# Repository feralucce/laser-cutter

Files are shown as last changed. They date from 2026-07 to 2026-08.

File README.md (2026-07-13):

# DIY Laser Cutter / Engraver

Design and build log for a homemade laser cutter and engraver.

## Repo layout

- `docs/decisions/` — Architecture Decision Records (ADRs). Each significant design choice (frame material, laser type/power, motion system, controller board, software stack, safety systems, etc.) gets its own numbered record: context, decision, consequences.
- `docs/` — general design notes, reference material, specs.

## Status

Just getting started. See `docs/decisions/` for the running log of decisions as we make them.

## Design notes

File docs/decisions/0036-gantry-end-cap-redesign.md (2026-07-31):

# 0036. Gantry end cap redesign: flat straddle plate, both ends identical

Date: 2026-07-14
Status: Superseded by [0047](0047-captured-belt-custom-plates.md) (supersedes [0016](0016-gantry-end-plate-rework.md) entirely)

## Context

[0016](0016-gantry-end-plate-rework.md)'s laminated fixed/floating
asymmetric pair existed to solve one problem: absorbing the 800mm beam's
length tolerance without needing an exact pre-cut length, since one end
had to be a precise reference and the other had to float.

[0035](0035-frame-corner-topology-rework.md) moves that tolerance-absorbing
job to the main frame's own corner joint (1200mm pieces sliding against
the 800mm end pieces before squaring). That removes the entire reason for
an asymmetric pair — **both gantry end caps can now be identical, flat,
and fully solid**, which is also the more rigid ("solid AF") joint that
motivated revisiting this in the first place.

The new topology ([0035](0035-frame-corner-topology-rework.md)) also
changes what this plate needs to physically span: the X-carriage (MGN12H
block) now rides on the **outside face** of the 1200mm frame piece, while
the beam sits at the gantry's own position along that rail. The end cap
plate needs to reach from the beam's end, across/past the 1200mm frame
piece, down to that carriage block — confirmed against a reference diagram
([docs/reference/frame-topology-sketch.svg](../reference/frame-topology-sketch.svg))
showing the relative positions of the 1200mm frame (red),
800mm end pieces (blue), the 800mm gantry beam (magenta), and the gantry
end caps (gold) straddling across the 1200mm rail to reach the carriage.

## Decision

One plate **design**, but each beam-end joint uses a **front + back pair**
(sandwiching the beam) — 2 ends x 2 plates (front, back) = 4 plate
assemblies total, all built from the same design (front and back are the
same shape; "both ends identical" means left-end pair = right-end pair).

- Each plate: **2 laminated layers, 3mm black acrylic** (6mm total) —
  thinner per-layer than [0029](0029-laser-cut-material-selection.md)'s
  general 5mm rule, a deliberate exception given these are now doubled up
  (front+back per end, 4 plates instead of 1) and don't need the
  T-slot-channel-replicating lamination trick [0016](0016-gantry-end-plate-rework.md)
  used ([0029](0029-laser-cut-material-selection.md) remains the default
  elsewhere, with this as a noted exception).
- **Beam attachment zone** (top of each plate): 3 connection points per
  plate (6 total per end, split across the front/back pair) —
  - 1 tapped screw into the beam extrusion's end bore (2040 has two
    internal channels; front plate uses one, back plate uses the other)
  - 2 L-bracket legs into that plate's own facing wide face's 2 T-slots
    (front plate → front wide face; back plate → back wide face) — outer
    layer solid, inner layer has cutouts for the L-brackets, same
    lamination principle as [0016](0016-gantry-end-plate-rework.md), just
    applied to both plates now instead of one.
- **Straddle zone** (middle of each plate): extends down/across, clearing
  the 1200mm frame piece's position, to reach the carriage block. Working
  estimate for this span — needs confirming once the beam/rail/carriage
  stack-up is physically known, same caveat pattern used for the Y-axis
  carriage bracket ([0032](0032-y-axis-laser-carriage.md)).
- **Carriage attachment zone** (bottom of each plate): MGN12H's standard
  20x20mm M3 bolt pattern, same as used throughout this build
  ([0013](0013-gantry-end-plate-design.md)) — both plates in the pair bolt
  through to the same block, sandwiching it.

Category: laser cut, 3mm black acrylic ([0003](0003-parts-sourcing-constraint.md)).

Design file: [hardware/laser-cut/gantry-end-cap.svg](../../hardware/laser-cut/gantry-end-cap.svg)
(one design, cut 8x total — 2 layers x 2 plates x 2 ends).

## Consequences

- Both gantry end caps are now identical — one design instead of two,
  simpler to cut/laminate/stock spares for.
- Bracket count for the gantry: **8 L-bracket legs total** (4 per end x 2
  ends) — both wide faces of the beam are now used at both ends, not just
  one face at one end as [0016](0016-gantry-end-plate-rework.md) originally
  had. This matters for [0028](0028-corner-bracket-hardware-selection.md)'s
  purchase quantity — revisit that count.
- Plus 4 tapped screws total (2 per end) — not L-brackets, ordinary M5
  bolts into the extrusion's own tapped end bore, no separate hardware
  purchase needed beyond generic screws.
- The old `gantry-end-plate-fixed.svg` and `gantry-end-plate-floating.svg`
  files are removed from the repo (superseded, preserved in git history) —
  a single new design file, `gantry-end-cap.svg`, replaces both.
- The straddle-zone span is a working estimate, not yet verified against
  physical assembly — same treatment as other "verify once hardware is in
  hand" items throughout this build.
- 2026-07-14 correction: the first version of `gantry-end-cap.svg` had the
  L-bracket slots at the wrong scale/orientation (10mm wide x 22mm tall,
  side by side) and one slot positioned entirely past the extrusion's real
  40mm-tall footprint (y=56-78 against an actual 8-48 span). Fixed by
  adding a dashed reference rectangle showing the true 20x40mm extrusion
  cross-section, and repositioning both slots (now 22mm wide x 10mm tall,
  rotated to match the wide-face-vertical orientation) fully within that
  reference. Slot dimensions remain a working estimate — redraw once the
  actual corner bracket's leg dimensions are confirmed
  ([0028](0028-corner-bracket-hardware-selection.md)), but they should now
  at least be plausibly located on the real material rather than floating
  in empty space.

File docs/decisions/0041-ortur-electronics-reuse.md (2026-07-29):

# 0041. Motion electronics: reuse Ortur LM2 S2 controller, drivers, motors, wiring, switches

Date: 2026-07-29
Status: Accepted (supersedes [0011](0011-x-axis-dual-motor.md), [0017](0017-stepper-motor-selection.md),
[0022](0022-controller-board-selection.md), [0026](0026-t41u5xbb-pin-mapping.md),
[0027](0027-grblhal-auto-square-config.md), [0037](0037-stepper-driver-selection.md))

## Context

This machine started as a ground-up custom build: new frame, new motion
system, and new electronics (grblHAL T41U5XBB + Teensy 4.1 controller,
STEPPERONLINE NEMA17 motors, STEPPERONLINE DM542T drivers), because the
project's starting point — an Ortur LM2 S2 already extended to 800x1200mm
with a 10W module — was assumed to need dual independently-driven,
firmware-synced X motors ([0011](0011-x-axis-dual-motor.md)) to keep a
1200mm-span gantry square, and the Ortur's stock closed-firmware GRBL
1.1f board can't do that kind of ganged/auto-square axis at all.

That assumption turns out to be wrong for this build. The Ortur LM2 S2,
at this exact 800x1200mm frame size, already drives its gantry/rail axis
(800mm, per [0043](0043-adopt-ortur-axis-convention.md)) with a **single
NEMA17 motor whose shaft is extended (via coupler + standoff) to reach
across and drive both sides of the gantry from one continuous shaft** —
manually squared once and locked in place. Squaring is inherent to the
mechanism (both sides are physically the same rotating shaft, not two
motors being kept in sync), not a firmware or electronic concern at all.
This is close to, but not exactly, the "single motor + mechanical link"
option [0011](0011-x-axis-dual-motor.md) originally considered and
rejected in favor of firmware ganging; that rejection was based on a
shaft/belt coupling across a long span being an unproven risk. It isn't
unproven — the Ortur has been cutting with a 10W module at this exact
frame size using exactly this mechanism. A K40-compatible adapter board
exists that lets the Ortur's stock controller drive the K40 laser module
in place of its own diode driver, closing the last gap (laser control)
that seemed to require a new controller.

Reusing the Ortur's controller, drivers, motors, wiring, and switches
removes the entire custom-electronics scope this project had taken on
(controller board selection/wiring/firmware, driver selection, motor
selection) without weakening anything — the mechanism is already proven
at this machine's actual size and load class, just with a lighter head.

## Decision

**Reuse from the existing Ortur LM2 S2 build, as-is:**
- Controller board (stock, GRBL 1.1f firmware)
- Stepper drivers (whatever the Ortur board integrates/uses)
- Steppers: **1 motor with an extended shaft (coupler + standoff) driving
  both sides of the gantry** on the rail/gantry-travel axis (Y, 800mm,
  per [0043](0043-adopt-ortur-axis-convention.md)); 1 separate motor on
  the beam/carriage axis (X, 1200mm) — this replaces this build's earlier
  assumption of 2 independently-driven motors on that axis
- Wiring harness
- Limit switches (X and Y homing switches)
- Laser control: via a K40-compatible adapter board that translates the
  Ortur controller's laser-control output to what the K40 module expects
  — exact product/model not yet identified, needs sourcing

**Squaring**: inherent to the mechanism — one continuous shaft (coupler +
standoff) turns both sides of the gantry together, so there's nothing to
electronically keep in sync. Squaring is a one-time mechanical alignment
at assembly (shaft/coupler position, locked with set screws), not a
runtime or firmware concern. No `$8`/`$170`/`$347-349` tuning, no
ganged-axis firmware build, and — unlike the originally-considered dual-
motor approach — no possibility of the two sides drifting out of sync
over time, since they're mechanically one shaft.

**Superseded ADRs**, no longer applicable to this build:
- [0011](0011-x-axis-dual-motor.md) — the "two independently-driven
  motors, synced in firmware" approach doesn't apply at all; this axis
  uses one motor and one continuous extended shaft instead
- [0017](0017-stepper-motor-selection.md) — motors are reused from the
  Ortur, not purchased
- [0022](0022-controller-board-selection.md) — controller is the Ortur's
  own stock board, not a new grblHAL Teensy build
- [0026](0026-t41u5xbb-pin-mapping.md) — no T41U5XBB in this build, pin
  mapping is moot
- [0027](0027-grblhal-auto-square-config.md) — no firmware auto-squaring;
  squaring is mechanical, done once at assembly
- [0037](0037-stepper-driver-selection.md) — drivers are reused from the
  Ortur, not purchased

**Still valid, unaffected by this ADR:**
- Frame dimensions/footprint ([0009](0009-frame-dimensions-final.md),
  [0035](0035-frame-corner-topology-rework.md)) and extrusion profile
  ([0010](0010-extrusion-profile-2040.md)) — new 2040 frame + gantry beam
  still being built, just carrying reused motion electronics instead of
  new ones
- Laser module selection ([0002](0002-laser-module-selection.md)) — K40
  unchanged
- Axis topology/naming ([0014](0014-axis-naming-convention.md)) — X/Y
  roles unchanged
- Gantry plates ([0040](0040-x-axis-v-wheel-gantry.md)) and laser
  carriage ([0032](0032-y-axis-laser-carriage.md)) — both already flagged
  as open, not-yet-designed work; unaffected by which controller drives
  the motors that move them

## Consequences

- Eliminates essentially the entire custom-electronics track of this
  project: no controller board to solder/wire/flash, no driver modules
  to mount, no motors to source, no firmware ganging to configure, no
  runtime `$` squaring tuning to commission.
- New open item: identify and source the specific K40-compatible adapter
  board that lets the Ortur's stock controller drive the K40 module —
  not yet a named product.
- Limit switch mounting design ([0033](0033-limit-switch-selection.md))
  is still real, open work (the new 2040 frame needs its own switch
  mounts), but the switch part itself and its hole spacing are now a
  known/reused quantity rather than an estimate pending physical
  hardware.
- Wiring harness is reused rather than newly run — the existing wiring
  diagram ([docs/reference/wiring-diagram.svg](../reference/wiring-diagram.svg))
  and fusing/gauge ADRs ([0025](0025-24v-rail-fusing.md),
  [0030](0030-24v-wire-gauge.md)) described a from-scratch harness for
  the new controller; that harness plan no longer applies and should be
  treated as historical, not a task to execute.
- The custom-controller design this project had built up through 2026-07-29
  is preserved in full on the `custom-controller-fallback` git branch, in
  case the Ortur-reuse approach hits a hardware blocker (e.g. the K40
  adapter board doesn't exist/work as expected) and this project needs to
  fall back to it.

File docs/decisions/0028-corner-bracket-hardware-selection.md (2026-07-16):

# 0028. Corner bracket hardware: product selection (dimension verification still pending)

Date: 2026-07-14
Status: Accepted

## Context

[0012](0012-corner-joints-and-feet.md) and [0016](0016-gantry-end-plate-rework.md)
both describe using "inside hidden corner bracket" style hardware (an
L-shaped cast bracket, one leg per T-slot face, tightened with a set
screw) for the frame corners and the gantry end plates — but neither ADR
ever linked a specific product. 0016 used working numbers (~19-20mm leg
length, M5 set screw, sized for a 6mm-wide/5.5mm-deep slot channel) and
flagged them as unverified.

Checked every retailer carrying this part style (Amazon, MakerTechStore,
OpenBuilds official store, Bulkman3D, RatRig, Maker Store) looking for a
dimensioned drawing. **None publish the leg length or set-screw position**
— this is a generic cast-zinc-alloy part cloned across many sellers, and
the only consistently published numbers are the overall footprint
(~25x10mm) and that the 20-series version takes M5 set screws. The 6mm
slot-channel width in 0016's working numbers is actually just the 20-series
T-slot extrusion's own standard channel width ([0010](0010-extrusion-profile-2040.md)),
not something specific to this bracket — that part of the working number
is solid. The leg length and set-screw offset genuinely cannot be
confirmed from any spec sheet; they can only be measured once a physical
unit is in hand.

## Decision

Purchase **[Inside Hidden Corner Bracket, 90°, M5 set screws, for 20mm x
20mm / 2020 / 20-series T-slot extrusion](https://www.amazon.com/Pack-Inside-Hidden-Corner-Bracket/dp/B06XZ3Z82M)**
(20-pack).

Quantity needed, updated 2026-07-15: **8** for the gantry (4 per end x 2
ends — both wide faces of the beam are now used at both ends, per the end
cap redesign, [0036](0036-gantry-end-cap-redesign.md)) + **8** for the
main frame rectangle corners (**2 per corner** — one bracket in each
T-slot at every corner, not just one, for a stronger joint than
[0012](0012-corner-joints-and-feet.md)'s original single-bracket-per-corner
default) = **16 total**, still covered by the 20-pack, now with only 4
spares.

Category: off-the-shelf.

## Consequences

- Closes the "which product" gap — there's now a specific SKU to order,
  where before there was only a hardware category description.
- Does **not** close the dimension-verification gap flagged in
  [0016](0016-gantry-end-plate-rework.md) — leg length and set-screw
  position remain working estimates until this specific part is physically
  in hand and measured with calipers. Cut the end plates only after that
  verification, or expect to re-cut if the slot/access-hole dimensions are
  off.
- The 6mm slot-channel width in the current end-cap design
  ([hardware/laser-cut/gantry-end-cap.svg](../../hardware/laser-cut/gantry-end-cap.svg),
  [0036](0036-gantry-end-cap-redesign.md)) is confirmed correct regardless
  (fixed by the extrusion standard, not the bracket) — only the slot depth
  and access-hole position depend on the actual bracket and remain
  unverified.

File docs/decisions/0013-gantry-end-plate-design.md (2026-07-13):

# 0013. Gantry end plate design

Date: 2026-07-13
Status: Accepted

## Context

The gantry crossbeam (2040, per [0010](0010-extrusion-profile-2040.md)) needs
to attach to the two Y-axis MGN12 carriage blocks
([0008](0008-motion-system-mgn12-rails.md), [0014](0014-axis-naming-convention.md))
at each end — the carriages riding the two guide rails that the whole
gantry travels along. Both mounting
interfaces are flat faces, which allows a single flat laser-cut plate rather
than a bent/welded bracket:

- The MGN12H carriage block has a 20mm x 20mm M3 bolt pattern on its top
  face.
- The 2040 beam's wide (40mm) face has two T-slots spaced 20mm apart,
  matching the standard 20-series M5 T-nut/screw standard.

The beam's end sits on top of the plate (screwed down into its own T-slots
via T-nuts), and the carriage block sits underneath (screwed up into its
threaded top holes) — no bent metal or 3D-printed part needed.

## Decision

Laser-cut flat plate, 50mm x 90mm, 3mm corner radius:

- Two M5 clearance holes (5.5mm dia), 20mm apart, centered on the plate
  width — for the 2040 beam's T-slot mounting.
- Four M3 clearance holes (3.5mm dia) in a 20x20mm square pattern — for the
  MGN12H carriage block.
- 15mm minimum edge margin around all holes for material strength in
  plywood/acrylic.

Design file: [hardware/laser-cut/gantry-end-plate.svg](../../hardware/laser-cut/gantry-end-plate.svg).
Category: laser cut ([0003](0003-parts-sourcing-constraint.md)).

## Consequences

- No 3D-printed or bent-metal bracket needed for this joint — a flat plate
  cut on the current laser handles it.
- Plate material/thickness not yet chosen (plywood vs acrylic, thickness) —
  needs to be picked before cutting; 15mm edge margins give some flexibility
  here.
- Two of these plates needed per machine (one per side of the gantry).
- All future laser-cut SVGs for this project include a 100mm x 10mm scale
  bar for import verification, per standing convention.
- **Open issue**: the gantry beam spans the long/flexible axis (X, up to
  1219mm) — it connects the two Y-axis guide rails, which are spaced apart
  by this dimension. The beam must be shorter than that spacing — it spans
  between the two carriages, which sit inboard of the Y-rails (mounted on
  the extrusion's inward-facing wide face). Exact beam length = the chosen
  X-axis spacing minus the Y-rail extrusion width, MGN12 rail/carriage
  offset, and this end plate's thickness, on both sides. Not yet
  calculated — needs final rail offset and plate material thickness before
  cutting the beam to length.
  Separately, the two **Y-axis guide rails themselves** are each 800mm long
  (the fixed axis, [0007](0007-frame-footprint-constraints.md)) — that
  figure is not affected by this clearance issue, since it's the guide
  rails' own length, not the beam's span.

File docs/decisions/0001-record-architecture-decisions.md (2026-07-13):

# 0001. Record decisions as ADRs

Date: 2026-07-13
Status: Accepted

## Context

This is a from-scratch DIY laser cutter/engraver build. We'll be making many
consequential choices (frame, laser source, motion system, electronics,
firmware/software, enclosure, safety systems) over time, and want a durable
record of why each choice was made, not just what was chosen.

## Decision

Record each significant design decision as a numbered markdown file in
`docs/decisions/`, following `template.md`. Use sequential numbering
(0001, 0002, ...). Mark a record "Superseded by NNNN" rather than editing
history when a decision changes.

## Consequences

Slight overhead per decision, but gives us a searchable history and lets
future us (or collaborators) understand the reasoning instead of just the
current state of the build.

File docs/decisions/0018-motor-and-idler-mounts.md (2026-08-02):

# 0018. Motor mount and idler mount hardware

Date: 2026-07-13
Status: Superseded by [0048](0048-captured-belt-both-axes-no-idler.md) (idler pulley/mount no longer needed; motor mount still applies where reused motors attach)

## Context

[0015](0015-x-axis-motor-system.md) decided motor and idler mounts should
be off-the-shelf (not 3D printed), since both are constantly-tensioned
anchor points where PLA-CF creep/flex would be a risk. Needed: specific
purchasable parts for both.

For the idler specifically: it only ever contacts the belt's smooth back
side (the toothed side stays engaged with the motor's drive pulley around
the whole loop), so the idler itself doesn't need teeth — a smooth pulley
or even a plain bearing works correctly. No clean single "bracket + pulley"
kit product was found; the standard/simpler approach is a smooth idler
pulley spinning freely on a bolt threaded into a T-nut in the extrusion
slot — fully off-the-shelf hardware, tension adjustable by sliding the
T-nut position before tightening, no dedicated bracket part needed.

## Decision

- **Motor mount**: [Socobeta 5PCS NEMA17 Stepper Motor Mounting
  Plate/Bracket, for 2020/2040 extrusion](https://www.amazon.com/Socobeta-Stepper-Mounting-Bracket-Aluminum/dp/B0FPMDHTHD).
  5-pack covers the 3 motors needed (2x X-axis, 1x Y-axis,
  [0011](0011-x-axis-dual-motor.md)) with 2 spares.
- **Idler mount**: bolt-on-T-nut approach (M5 socket-head bolt + washers/
  spacers for height + T-nut), no separate bracket product.
- **Idler pulley**: [DiGiYes GT2 Timing Belt Idler Pulley, 20-toothless
  (smooth), 5mm bore, for 6mm belt width](https://www.amazon.com/gp/product/B0BSPC7D9S/).
  User-sourced. Matches requirement: smooth-riding (teeth not required, and
  this part is genuinely toothless rather than a repurposed drive pulley),
  5mm bore (matches M5 bolt and the [0017](0017-stepper-motor-selection.md)
  motor's shaft size for hardware consistency), sized for the 6mm GT2 belt
  ([0015](0015-x-axis-motor-system.md)).

**Update (2026-07-29)**: the bolt-on-T-nut hardware approach above assumed
buying the OpenBuilds-style bolt+spacer+locknut kit for the idler mount —
that kit is no longer available. Switching to a **3D-printed PLA-CF idler
mount** instead: [JeSc HyperCube XY Idler T16 v2.0](https://www.printables.com/model/56963-jesc-hypercube-xy-idler-t16-v20/files)
(originally a HyperCube CoreXY 3D printer part), downloaded to
[Printables/](../../Printables/) in this repo. User already has PLA-CF
filament on hand.

This reopens the concern this ADR's own Context section originally raised
against printing the idler mount — "constantly-tensioned anchor points
where PLA-CF creep/flex would be a risk" — but it's directly addressed:
**printing solid (100% infill)**, not the typical partial-infill
approach. Solid PLA-CF removes the creep/flex mechanism that concern was
about (infill-cavity walls slowly deforming under sustained load); a
solid print behaves much closer to a machined block than a typical
lightweight 3D print. Accepted as resolved, not just deferred.

User will also modify the model file directly if the pulley mount
geometry doesn't fit the DiGiYes idler once test-fit — treat the
Printables download as a starting point, not a fixed, unmodifiable file.

**Not yet verified**: whether the print's pulley bore/mount geometry
fits the already-purchased [DiGiYes GT2 20T idler pulley](https://www.amazon.com/gp/product/B0BSPC7D9S/)
as downloaded, before any modification. Tooth count isn't the concern —
idler pulleys are smooth/toothless by design (this build's own reasoning
above, and presumably true of the original HyperCube idler this print was
made for too), so the "T16" in the model's name is about GT2 belt-pitch
compatibility generally, not a mismatched mating tooth count. What
actually needs checking is the idler's physical bore diameter, outer
diameter, and width against what this bracket's mount was sized for —
same "verify against physical hardware" pattern used throughout this
build's other parts, with the fallback that it's a known-editable file
if it doesn't.

**Print settings**: PLA-CF, **100% (solid) infill** — deliberately
different from this build's other printed parts, which use 15% infill
([0040](0040-x-axis-v-wheel-gantry.md)); solid infill specifically to
resolve the creep/flex concern for this constantly-tensioned part.

Category: mostly off-the-shelf (idler pulley, motor mounts); idler mount
bracket now 3D-printed PLA-CF instead of off-the-shelf hardware.

## Consequences

- One consistent hardware size (5mm/M5) across idler bore, idler mounting
  bolt, and motor shaft — simplifies the parts list.
- Idler tensioning is manual (slide T-nut, tighten) rather than a
  dedicated adjustable-slot bracket mechanism — simple but requires loosening
  and re-tightening the bolt to adjust tension, rather than a quick-adjust
  slot.
- Idler pulley now sourced — motor-side pulley hardware list
  ([0017](0017-stepper-motor-selection.md), [0019](0019-drive-pulley-selection.md),
  this ADR) is complete.

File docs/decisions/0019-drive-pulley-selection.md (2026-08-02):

# 0019. Drive pulley (motor gear) selection

Date: 2026-07-13
Status: Superseded by [0048](0048-captured-belt-both-axes-no-idler.md) (captured-belt drive pulley now mounts between the wheels directly on both axes)

## Context

[0015](0015-x-axis-motor-system.md) specified GT2 20-tooth, 5mm bore
pulleys for the motor side of each belt loop, but no specific product had
been sourced yet.

## Decision

**[BEMONOC 2GT Timing Pulley, 20 teeth, 5mm bore, for GT2 6mm belt](https://www.amazon.com/BEMONOC-Timing-Pulley-Teeth-Printer/dp/B014ID115W)**

Matches spec exactly: 20-tooth, 5mm bore (fits the
[0017](0017-stepper-motor-selection.md) motor's shaft), sized for the 6mm
GT2 belt ([0015](0015-x-axis-motor-system.md)), set-screw mounting.

Quantity: 3 (one per motor — 2x X-axis, 1x Y-axis, [0011](0011-x-axis-dual-motor.md)).

Category: off-the-shelf.

## Consequences

- Completes the drive-side hardware list for the belt loops: motor
  ([0017](0017-stepper-motor-selection.md)), drive pulley (this ADR),
  idler pulley (pending link, [0018](0018-motor-and-idler-mounts.md)),
  motor mount ([0018](0018-motor-and-idler-mounts.md)).
- Still open: belt clamp/clip to anchor the belt to each carriage.

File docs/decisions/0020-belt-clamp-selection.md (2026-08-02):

# 0020. Belt clamp selection and mounting

Date: 2026-07-13
Status: Superseded by [0048](0048-captured-belt-both-axes-no-idler.md) (captured belt now on both axes; belt ends anchored by the GT2 fixing clamp instead)

## Context

[0015](0015-x-axis-motor-system.md) flagged the belt clamp (anchoring each
belt end to the carriage) as an open item. Each X-rail runs an open belt
loop — both ends terminate at clamps on the same carriage/end plate, rather
than a single continuous loop — so tension can be fine-adjusted
independently at each end by how far the belt is threaded through its
clamp before tightening.

## Decision

**[3DMAN GT2 Timing Belt Aluminum Gear Clamp Mount Block, 9x40mm, for 6mm
belt width (10-pack)](https://www.amazon.com/3Dman-Timing-Aluminum-Clamp-9X40mm/dp/B08XVVQW6G/)**

40 x 9 x 5mm aluminum block, single 4.5mm center mounting hole (M4 screw).
10-pack covers the 4 needed (2 per side x 2 sides) with spares.

**Mounting**: one clamp per belt end, both on the same gantry end plate
([0016](0016-gantry-end-plate-rework.md)) since both belt ends terminate at
the same carriage. Added to the **outer layer** of each end plate (fixed
and floating), in the left/right margins beside the existing carriage-mount
hole pattern, oriented with the clamp's 40mm length running parallel to the
plate's long axis (matching the belt's direction of travel along the
X-rail):

- Clamp hole 1: (6, 65) — left margin
- Clamp hole 2: (44, 65) — right margin

Both positions verified clear of the existing 4x M3 carriage-mount holes
(at x=15/35) and the plate edges/corner radius.

Category: off-the-shelf.

## Consequences

- Closes out the last open item from [0015](0015-x-axis-motor-system.md)'s
  belt/pulley hardware list.
- Exact clamp position is a reasonable placement based on published
  dimensions, not verified against a physical mockup — worth confirming
  the belt actually reaches both clamp points cleanly once the carriage,
  rail, motor, and idler are physically laid out; may need minor
  adjustment.
- Both end plate SVGs ([hardware/laser-cut/gantry-end-plate-floating.svg](../../hardware/laser-cut/gantry-end-plate-floating.svg),
  [hardware/laser-cut/gantry-end-plate-fixed.svg](../../hardware/laser-cut/gantry-end-plate-fixed.svg))
  updated with these 2 holes on the outer layer.

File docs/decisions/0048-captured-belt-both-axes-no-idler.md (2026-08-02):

# 0048. Captured belt drive on both axes; idler pulleys eliminated

Date: 2026-07-31
Status: Accepted (extends [0047](0047-captured-belt-custom-plates.md) to X; supersedes [0018](0018-motor-and-idler-mounts.md)'s idler pulley/mount, [0019](0019-drive-pulley-selection.md) where it specified an idler-loop system)

## Context

[0047](0047-captured-belt-custom-plates.md) adopted captured-belt drive
for the Y-axis (short, 800mm, dual-rail/shaft-driven) gantry plates.
The X-axis (long, 1200mm, single-motor carriage) had been left on the
original open-loop belt design (drive pulley + idler pulley + belt
clamps at each end).

User has now extended captured-belt routing to X as well. A captured
belt path doesn't need a separate idler pulley — the belt threads
directly under the traveling wheels rather than needing a dedicated
return pulley at the far end of an open loop. This removes the idler
pulley (and its mount) from the design entirely, on both axes.

## Decision

- Captured belt drive on **both axes** (X and Y), not just Y.
- **DiGiYes idler pulley**: no longer needed anywhere in the design.
- **Idler mount bracket** (JeSc HyperCube XY Idler T16 v2.0, the
  project's last remaining 3D-printed part): no longer needed, removed
  from `hardware/3d-printed/`.
- **The GT2 fixing clamp becomes the only 3D-printed part in this
  build**: [hardware/3d-printed/gt2-fixing-clamp.stl](../../hardware/3d-printed/gt2-fixing-clamp.stl)
  (source: user-downloaded model, "gt2-belt-clamp-techguy"). Anchors the
  captured belt's ends. Qty: **8** (per-axis-end anchor points across
  both axes). Print PLA-CF, solid (100% infill) — same creep-resistance
  rationale already established for this project's other tensioned
  printed parts.
- `hardware/3d-printed/` cleaned out — all previously-superseded
  drafts (limit-switch-mount, shaft-far-end-bearing-mount,
  y-carriage-k40-bracket, y-gantry-plate) removed outright rather than
  kept for reference, since none of them represent live geometry
  anymore and this project's git history already preserves them if
  ever needed.

## Consequences

- BEMONOC drive pulley and 3DMAN belt clamp purchases (0019/0020) are
  no longer part of this design on either axis — captured belt uses the
  drive pulley mounted between the wheels directly, and the GT2 fixing
  clamp anchors the belt ends instead of the 3DMAN clamps.
- BOM updated: DiGiYes idler pulley removed from Motion system; 3D-printed
  parts section now lists only the GT2 fixing clamp, qty 8.
- Belt clamp/idler pulley hardware already purchased for the original
  open-loop design is simply not part of this design going forward —
  not something to manage or return, the user's own call.

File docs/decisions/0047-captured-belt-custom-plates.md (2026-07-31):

# 0047. Y-axis gantry plates: back to captured belt, custom laser-cut acrylic

Date: 2026-07-29
Status: Accepted (supersedes [0046](0046-shaft-driven-open-belt.md); reinstates the captured-belt approach from [0042](0042-captured-belt-drive.md))

**Also supersedes**: [0036](0036-gantry-end-cap-redesign.md) — this Y
gantry plate design *is* the gantry end cap, doing the same job
(terminating the beam, mounting to the gantry plates); it isn't a
separate part alongside `gantry-end-cap.svg`. That file and this ADR's
carriage-attachment-zone open item are both closed out by this design.

## Context

[0046](0046-shaft-driven-open-belt.md) moved away from captured-belt
routing specifically to avoid needing to match the purchased aluminum
V-wheel plate's exact wheel geometry. That constraint is now gone: the
user is designing **custom gantry plates from scratch** (reusing only
the wheels/wheel-bolts from the purchased kit, not the kit's own plate),
directly informed by two real reference files
(`Printables/yplateleft.stl`, `Printables/yplateright.stl`) that already
solve this exact captured-belt layout — motor or bearing centered, 2 top
wheels flanking the shaft, a bottom wheel, and 2040 mounting holes. With
a real reference geometry in hand, captured-belt is no longer a fitting
problem — it's just a matter of drawing the plate.

Two further changes from that reference:
- **3 bottom wheels instead of 1** (2 top unchanged) — more load support
  under the gantry's weight, all 3 using the same wide/eccentric-nut-
  clearance hole style the reference used for its single bottom wheel.
- **4 additional M5 holes per plate for corner L-brackets** — the
  "FOR 20 SERIES ALUMINUM PROFILE RAIL" corner bracket (26mm tall leg,
  25mm long leg, M5, hole 6mm in from the bend), seated in the 2040
  beam's own V-slot channel and bolted to the plate, for squareness/
  rigidity — not a flat face-mount bracket.
- **Material: laser-cut black acrylic, not 3D-printed PLA-CF.** The
  shaft-far-end bearing bracket ([shaft-far-end-bearing-mount.scad](../../hardware/3d-printed/shaft-far-end-bearing-mount.scad))
  and the first pass at this plate ([y-gantry-plate.scad](../../hardware/3d-printed/y-gantry-plate.scad))
  were both designed as 3D-printed parts before this correction — both
  superseded, kept for reference/coordinate history only.

## Decision

**Design file**: [hardware/laser-cut/y-gantry-plate.svg](../../hardware/laser-cut/y-gantry-plate.svg)
— **authored directly by the user in Inkscape** (my earlier programmatic
draft was replaced outright, not merged), two variants (motor side,
bearing side).

**Attachment to the 2040 beam: 6 points per plate**:
- **2 tapped directly into the extrusion's end grain** (threaded holes,
  not T-slot) — positioned near the shaft/motor bore
- **4 through slotted holes for 20-series corner L-brackets** (the ones
  seated in the extrusion's V-slot, see the "FOR 20 SERIES ALUMINUM
  PROFILE RAIL" hardware from earlier conversation) — **slotted, not
  round**, specifically because no reliable dimensional reference exists
  for that hardware to place a fixed hole accurately; slots absorb the
  uncertainty, same philosophy as this project's other not-yet-verified
  parts (idler mount, corner brackets)

Other hole layout (both variants share everything except the center
mount) matches the reference plates and my earlier draft's data — 2 top
wheels, 3 bottom wheels (wide/eccentric-nut style), NEMA17 or 625ZZ
bearing at center. The outer boundary is a plain rectangle (~87.26mm x
~160.75mm), not the organic shield shape from the reference STLs — the
user deliberately simplified it, matching the same call I'd made
independently in the draft this supersedes.

**Superseded**: [0046](0046-shaft-driven-open-belt.md) (open belt loop,
2 pulleys) — captured-belt routing from [0042](0042-captured-belt-drive.md)
is reinstated. [0018](0018-motor-and-idler-mounts.md)'s idler
pulley/mount and [0019](0019-drive-pulley-selection.md)'s drive pulley
selections still apply to the X-axis (unaffected), but no longer apply
to the Y-axis the way 0046 had them wired up.

## Consequences

- The purchased BEMONOC/DiGiYes pulleys and 3DMAN belt clamps
  ([0046](0046-shaft-driven-open-belt.md)'s reinstated hardware) are no
  longer part of the Y-axis mechanism — still usable on X, which keeps
  its own motor/pulley/belt-clamp setup unaffected by this ADR.
- Wheels and wheel-bolts are reused from the purchased aluminum V-wheel
  plate kit (0040) — its own plate is not used, only its wheel hardware.
- **Not yet confirmed**: acrylic thickness isn't specified in the SVG
  itself (project default is 5mm, 0029; reference 3D-printed plates were
  8mm) — worth a real check before committing to a full cut.
- Bottom wheel X-alignment is resolved — the user's own file confirms
  the layout, no longer an open question.
- 3D-printed versions of both the gantry plate and the far-end bearing
  bracket are superseded and kept only for reference/coordinate history,
  not built.

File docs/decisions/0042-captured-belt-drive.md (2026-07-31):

# 0042. Belt routing: captured belt drive (Ortur style), not clamped-both-ends

Date: 2026-07-29
Status: Reinstated by [0047](0047-captured-belt-custom-plates.md) (briefly superseded by [0046](0046-shaft-driven-open-belt.md)) (supersedes [0020](0020-belt-clamp-selection.md); modifies
[0018](0018-motor-and-idler-mounts.md), [0019](0019-drive-pulley-selection.md),
[0040](0040-x-axis-v-wheel-gantry.md))

## Context

[0020](0020-belt-clamp-selection.md) designed an open belt loop with both
ends clamped directly to the carriage/end plate (3DMAN aluminum clamp
blocks, bolted on either side of the carriage-mount hole pattern) — the
standard MGN-rail-carriage belt anchoring style this project had been
assuming.

The Ortur LM2 S2, which this build is now reusing the controller/drivers/
motors/wiring/switches from ([0041](0041-ortur-electronics-reuse.md)),
uses a different belt path: a **captured belt drive**. The belt is fed
under the gantry's and carriage's V-wheels (the wheel presses the belt
against the rail/plate as it travels, capturing it in place along the
run) and over the timing gear (the motor's drive pulley) at the fixed
end. This is a continuous routed path along the wheel track, not a
short open loop clamped at both ends to a stationary carriage plate.

This build is already using V-wheel gantry plates on X
([0040](0040-x-axis-v-wheel-gantry.md)) and wheels as Y-carriage
reinforcement ([0039](0039-y-axis-single-rail-dual-block.md)) — the
wheel hardware needed for a captured-belt path is already the planned
mechanism, just not yet the belt routing built around it.

## Decision

Adopt the Ortur's captured belt drive routing for both axes: belt runs
under each gantry-plate/carriage wheel along the rail, over the drive
pulley (timing gear) at the motor end. No dedicated belt-clamp hardware
bolted to the carriage/end plate.

**Superseded**: [0020](0020-belt-clamp-selection.md) (3DMAN clamp
blocks) — no longer needed in this design.

**Open, not yet resolved by this ADR**:
- The new custom gantry plates ([0040](0040-x-axis-v-wheel-gantry.md))
  and laser carriage ([0032](0032-y-axis-laser-carriage.md)) — both
  already open design tasks — now need to incorporate a belt-capture
  channel/track under each wheel, matching the Ortur's geometry, not
  just a bolt pattern. This is a real addition to the scope of those
  two open tasks, not a separate task.
- Whether the already-purchased BEMONOC drive pulley and DiGiYes idler
  pulley ([0018](0018-motor-and-idler-mounts.md),
  [0019](0019-drive-pulley-selection.md)) are dimensionally compatible
  with captured-belt routing (belt needs to sit flush under the wheels
  and mesh cleanly at the pulley without slack or excess pinch) — not
  yet checked. If not compatible, the Ortur's own drive/idler pulleys
  (already proven with this exact routing) are the fallback, consistent
  with [0041](0041-ortur-electronics-reuse.md)'s reuse approach.
- Belt end termination: even a captured-belt path still needs the belt's
  two ends fixed somewhere (typically at the carriage) — mechanism not
  yet designed, just no longer the 3DMAN clamp-block approach.

## Consequences

- Removes the previously-purchased 3DMAN GT2 belt clamps from this
  design's scope (still bought, just not part of this design —
  [0041](0041-ortur-electronics-reuse.md)'s reuse pivot already
  established this "bought but not needed" pattern for other parts).
- Ties belt routing directly to the gantry-plate/carriage design work
  that was already open — raises the bar on that design task (needs a
  wheel-track belt channel, not just bolt holes) but doesn't add a new
  task to the list.
- Pulley compatibility with this routing is a new, real open
  verification item alongside the existing "verify against physical
  hardware" items already tracked for this build.

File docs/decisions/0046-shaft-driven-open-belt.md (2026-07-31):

# 0046. Belt drive: shaft-driven open belt loops (both sides), not captured-under-wheel

Date: 2026-07-29
Status: Superseded by [0047](0047-captured-belt-custom-plates.md) (supersedes [0042](0042-captured-belt-drive.md); reinstates [0020](0020-belt-clamp-selection.md))

## Context

[0042](0042-captured-belt-drive.md) adopted the Ortur's captured-belt
mechanism (belt fed under the gantry wheels, over a pulley positioned
between the top two wheels) after the user described it verbally.
Reference photos of the actual Ortur mechanism confirmed the belt-under-
wheel description is accurate for the Ortur's own build, but matching it
exactly requires positioning a motor-mount/shaft assembly relative to
the specific wheel layout of **our purchased aluminum V-wheel plate**
(0040) — a different product than the Ortur's own 3mm acrylic plate,
with its own (not fully confirmed) 6-wheel layout.

Simpler alternative: keep the single-motor-plus-extended-shaft mechanism
(0041 — still one motor, one continuous shaft spanning the Y axis,
inherently squared since both drive points are the same physical shaft),
but put a **drive pulley at each end of the shaft** feeding a
conventional **open belt loop per side**, clamped to each gantry-leg's
carriage at one end and running to a fixed idler pulley at the other —
rather than threading the belt under each wheel. This is mechanically
equivalent for squaring purposes (still one rigid shaft, still
inherently synchronized, still nothing to keep in sync electronically)
without needing to match the captured-belt geometry to this specific
plate's wheel positions.

This also reinstates hardware already purchased for the original
custom-build plan and not wasted by any pivot so far: Socobeta motor
mounts, BEMONOC drive pulleys, DiGiYes idler pulleys, 3DMAN belt clamps
— all sized and quantified for exactly this kind of open-loop belt
system.

## Decision

- **Shaft mechanism unchanged from [0041](0041-ortur-electronics-reuse.md)**:
  one NEMA17 motor, shaft extended via coupler + standoff, spanning the
  full Y-axis (800mm) width.
- **Drive pulleys**: one GT2 20T pulley at each end of the shaft (motor
  end and far end) — BEMONOC pulleys already purchased.
- **Belts**: one open-loop GT2 belt per side (2 total for Y), each
  clamped to its own gantry-leg's carriage plate at the driven end, and
  running to a fixed idler pulley (DiGiYes, already purchased) at the
  frame-mounted far end of that side's rail.
- **Belt clamps**: 3DMAN clamps (already purchased) anchor each belt to
  its gantry-leg carriage — reinstates [0020](0020-belt-clamp-selection.md).

**Superseded**: [0042](0042-captured-belt-drive.md) — no captured/under-
wheel belt routing in this design.

**New open design task**: a motor-mount plate (holds the NEMA17 next to
one gantry-leg's carriage) and a shaft-support/standoff mount (supports
the shaft's far end at the other gantry-leg's carriage) — both need to
be designed from scratch, since this is a new frame, not the Ortur's own.
Reference photos of the Ortur's own motor-mount and shaft-standoff
mounts (from this conversation) are a useful visual starting point for
the general approach (bracket holding motor next to the wheel plate,
coupler-into-standoff on the far side), not a dimensioned template.

## Consequences

- No geometry dependency on the purchased aluminum plate's exact wheel
  layout for the belt mechanism — removes an open question that was
  blocking progress.
- Reinstates already-purchased hardware (Socobeta, BEMONOC, DiGiYes,
  3DMAN) that [0042](0042-captured-belt-drive.md) had made unnecessary —
  nothing wasted, no new purchases needed for the belt/pulley/clamp
  hardware itself.
- Real new design task: motor-mount plate + shaft-support/standoff mount,
  both attaching to the purchased aluminum gantry plates. Joins the
  existing open list (gantry end cap redesign, limit switch mount, idler
  mount print/fit check) as a 4th real design task.
- BOM's belt-routing note reverts to reflect open-loop clamps.

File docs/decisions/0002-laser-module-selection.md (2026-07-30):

# 0002. Laser module: LaserTree K40 (40W+ optical)

Date: 2026-07-13
Status: Accepted (briefly superseded by [0044](0044-laser-module-k30.md), reinstated by [0045](0045-revert-to-k40.md))

## Context

Starting point is an Ortur LM2 S2 with a 10W optical module. Goal is to reliably
cut 1/2" (12.7mm) Baltic birch plywood (laser-grade, void-free). The Ortur's
stock module and frame are not enough, and Ortur only officially supports up
to 10W on that platform anyway — so this is not an upgrade of the Ortur, it's
a new custom machine designed around a more powerful module.

We're buying the new laser module from LaserTree. Their relevant lineup
(optical output, not diode input power):

| Module | Optical power | Weight | Size (LxWxH) | Power draw | Price |
|---|---|---|---|---|---|
| K30 | 30W (measured ~34.2W) | 710g | 66x64x134mm | 24V/5A (120W) | $449 |
| K40 | 40W+ (measured ~44W) | 900g | 66x66x134mm | 24V/6A (144W) | $549 |
| K60 (switchable 20/40/60W) | up to 60W+ (measured ~70W) | 1263g | 76x83x178mm | 24V/10A (240W) | $829 |

Research (LaserTree's own cutting data plus independent tests) on cutting
12mm/15mm plywood:
- K30 is rated for 15mm plywood in one pass per LaserTree's own chart, but a
  separate MDF test needed ~4 passes at 12mm — borderline for dense hardwood
  ply, likely multiple passes with more heat/char risk.
- K40 is rated for 9mm MDF-15mm plywood, with one-pass claims up to 30mm pine.
  An independent test cut 12mm hardwood plywood cleanly in one pass at
  ~240mm/min. A K60 running at its 40W setting (same optical power as a K40)
  one-pass cut 15mm plywood at 160mm/min.
- K60 gives large headroom (up to 60W) but at ~1.8x the K30 price, 1.4x the
  K40 weight, and a noticeably larger footprint (76x83x178mm vs 66x66x134mm)
  — that ripples into needing a heavier gantry, stronger steppers, bigger
  rails, and a bigger frame than 12.7mm plywood actually requires.

## Decision

Use the **LaserTree K40** (40W+ optical, ~44W measured) as the laser module
for this build.

It clears the bar for cutting 1/2" Baltic birch (one slow pass, or two passes
at a more practical/cleaner speed) with real margin over the K30, while
staying light and compact enough (900g, 66x66x134mm) to build a reasonably
sized DIY gantry around, unlike the K60.

## Consequences

This module drives several downstream requirements for the machine design:

- **Power supply**: needs at least 24V/6A (144W). Confirmed via the K40's
  kit contents photo that this is **included** — ships with a 24V/8A power
  adapter and matching driver-adapter input cable, no separate sourcing
  needed. Motors/controller electronics are powered by a separate PSU, see
  [0023](0023-power-supply-selection.md).
- **Air assist**: the K40 has a built-in air assist nozzle, but needs an
  **external air pump/compressor** — not included, must be sourced separately
  (falls under the "off the shelf" component category).
- **Mounting**: module uses a "2EDG-3.81" electrical interface and ships with
  a sliding plate with M5/M3 mounting holes. The X-carriage/gantry mount needs
  to be designed (3D printed or laser cut) to accept this plate.
- **Carriage weight budget**: at 900g, the X-axis carriage, belt, and motor
  need to be sized to move this mass accurately at cutting speeds — this
  weight becomes a constraint on the motion system design (next decision).
- **Cooling/ventilation**: cutting at these power levels for 1/2" ply produces
  meaningful smoke/fumes — enclosure and exhaust design should account for
  this from the start, not be retrofitted.

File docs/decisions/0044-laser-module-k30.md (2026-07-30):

# 0044. Laser module: switch to LaserTree K30 (30W optical)

Date: 2026-07-29
Status: Superseded by [0045](0045-revert-to-k40.md) (supersedes [0002](0002-laser-module-selection.md))

## Context

[0002](0002-laser-module-selection.md) picked the K40 over the K30
because the stated goal at the time was reliably cutting 1/2" (12.7mm)
Baltic birch plywood in one pass — the K30 was found borderline for that
(LaserTree's own chart rates it for 15mm in one pass, but an independent
MDF test needed ~4 passes at 12mm).

The actual, real-world use case is different: primarily cutting **3mm
and 6mm** Baltic birch plywood, with **12mm as an occasional case that
can be laminated from thinner layers** rather than needing routine
single-pass 12mm cutting. Under that actual usage, the K30's one-pass
15mm rating clears the 12mm ceiling with margin, and the borderline
concern that ruled it out in 0002 doesn't apply — 3/6mm are trivial for
a 30W module.

## Decision

**LaserTree K30** (30W optical, ~34.2W measured), $449, 710g, 66x64x134mm,
24V/5A (120W) — https://lasertree.com (K30 30W Optical Power Laser Module).

## Consequences

- **Lighter carriage load**: 710g vs the K40's 900g — a real plus for
  the captured-belt carriage design ([0042](0042-captured-belt-drive.md))
  and the not-yet-designed laser carriage ([0032](0032-y-axis-laser-carriage.md)),
  both still open tasks. Any dimension/weight-budget reasoning in older
  ADRs referencing "900g K40" should be read as 710g going forward.
- **Lower cost**: $449 vs $549.
- **Lower power draw**: 24V/5A (120W) vs 24V/6A (144W) — worth
  double-checking against the PSU headroom ([0023](0023-power-supply-selection.md)),
  though the PSU was already sized well above either module's draw.
- **Mounting interface not yet confirmed identical to the K40's**: 0002
  recorded the K40's mounting as a sliding plate with M5/M3 holes and a
  115mm height-adjustment slide rail. Whether the K30 shares this exact
  interface (same LaserTree K-series family, so plausible) isn't
  confirmed — worth checking against the physical module once in hand,
  same "verify against real hardware" caveat this project already
  applies elsewhere.
- Air assist, PSU, and all other downstream requirements from 0002 are
  otherwise unaffected — the K30 still needs external air assist and its
  own bundled 24V supply, same as the K40 did.
- BOM's "still ordering" line updated to K30.

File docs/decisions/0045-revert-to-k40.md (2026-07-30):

# 0045. Laser module: revert to K40 — power headroom over K30

Date: 2026-07-29
Status: Accepted (supersedes [0044](0044-laser-module-k30.md); reinstates [0002](0002-laser-module-selection.md)'s K40 choice)

## Context

[0044](0044-laser-module-k30.md) switched to the K30 based on real usage
being primarily 3mm/6mm plywood with 12mm as an occasional laminated
case. That reasoning wasn't wrong, but it undervalued one asymmetry:
**laser power can always be dialed down in software, but never dialed up
past a module's physical capacity.** A K40 run at K30-equivalent power
for the common 3/6mm jobs costs nothing extra day-to-day, while keeping
the headroom to single-pass thicker/denser material later without being
capped by the module itself.

The user has already placed the order for the K40.

## Decision

**Revert to the LaserTree K40** (40W+ optical, ~44W measured), $549,
900g, 66x66x134mm, 24V/6A (144W) — reinstating [0002](0002-laser-module-selection.md)'s
original selection and its full reasoning.

## Consequences

- BOM reverted: "still ordering" line, adapter board reference, and
  known-open-verification-items entries all go back to referencing the
  K40 (as they did before [0044](0044-laser-module-k30.md)).
- Carriage/mounting weight budget reverts to 900g (not 710g) — any
  not-yet-designed part sized against the laser module's mass (laser
  carriage, [0032](0032-y-axis-laser-carriage.md); captured-belt gantry
  plate, [0042](0042-captured-belt-drive.md)) should use the K40's
  figure.
- K40's mounting interface (sliding plate, M5/M3 holes, 115mm height-
  adjust slide, [0032](0032-y-axis-laser-carriage.md)) is the one
  already documented from 0002 — no new verification item introduced by
  this revert, unlike 0044's open question about the K30's interface.
- Power draw reverts to 24V/6A (144W) from the K30's 120W — already
  accounted for in the PSU sizing ([0023](0023-power-supply-selection.md)).

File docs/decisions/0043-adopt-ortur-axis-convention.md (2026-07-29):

# 0043. Axis naming: adopt Ortur's own X/Y convention

Date: 2026-07-29
Status: Accepted (supersedes [0014](0014-axis-naming-convention.md))

## Context

[0014](0014-axis-naming-convention.md) deliberately chose the *opposite*
of Ortur's own axis naming: X = the long 1200mm axis (whole gantry
travel), Y = the short 800mm axis (beam-mounted carriage). That made
sense when this was a from-scratch custom build with its own
controller/firmware being configured from zero.

It no longer makes sense now that the controller, drivers, motors,
wiring, and firmware are all being reused directly from the Ortur
([0041](0041-ortur-electronics-reuse.md)) — the Ortur's own firmware,
motherboard silkscreen labels, wiring harness connectors, and any
support material (manuals, replacement-part listings, forum threads) all
use Ortur's convention. Keeping a project-invented reversed convention on
top of physically reused Ortur hardware/firmware is a real
mislabeling risk, not just a documentation inconsistency — e.g. wiring
the reused "Y motor" to what this project's old ADRs called "X" would be
backwards from how the harness is actually terminated.

**Confirmed Ortur convention, corrected**: initial research (Ortur's
stock Y-axis extension kit, which stretches the *stock* 390x410mm working
area to 390x800mm) led to an incorrect assumption that Y is always the
longer axis. That's only true for the *stock* kit's own numbers — it
doesn't hold for this specific machine. Per the user directly (owns and
has physically extended this exact machine): **the gantry rides on the
800mm axis**, not the 1200mm one. This machine's 1200mm dimension comes
from a further **custom** beam elongation beyond what Ortur's stock kit
offers (the stock kit only reaches 800mm on the rail axis; reaching
1200mm on the *other* axis is a separate, non-stock modification the
user already did). So on this specific machine: **Y = the short 800mm
axis** (gantry/rail travel, stock-kit-extended), **X = the long 1200mm
axis** (custom-elongated beam, carriage travel).

## Decision

Adopt Ortur's own convention, matching this specific machine's actual
extended geometry:

- **Y-axis = the short axis (800mm).** Two guide rails, one NEMA17 motor
  with an extended shaft (coupler + standoff) driving both sides from a
  single continuous shaft ([0041](0041-ortur-electronics-reuse.md)),
  whole gantry (beam + carriage) travels along these — this is the axis
  reached via Ortur's stock Y-extension kit.
- **X-axis = the long axis (1200mm).** Single MGN12 rail on the gantry
  beam itself (custom-elongated beyond stock), single NEMA17 motor,
  laser carriage (holding the K40) travels the full 1200mm along this
  beam.

**Critical translation note**: every ADR in this repo written before
this one — [0008](0008-motion-system-mgn12-rails.md),
[0011](0011-x-axis-dual-motor.md), [0014](0014-axis-naming-convention.md),
[0015](0015-x-axis-motor-system.md), [0016](0016-gantry-end-plate-rework.md),
[0019](0019-drive-pulley-selection.md), [0020](0020-belt-clamp-selection.md),
[0021](0021-y-axis-motor-system.md), [0026](0026-t41u5xbb-pin-mapping.md),
[0027](0027-grblhal-auto-square-config.md), [0032](0032-y-axis-laser-carriage.md),
[0035](0035-frame-corner-topology-rework.md), [0036](0036-gantry-end-cap-redesign.md),
[0038](0038-y-axis-dual-rail.md), [0039](0039-y-axis-single-rail-dual-block.md),
[0040](0040-x-axis-v-wheel-gantry.md), [0041](0041-ortur-electronics-reuse.md),
[0042](0042-captured-belt-drive.md) — uses the **old, now-reversed**
convention throughout their text (X = long/whole-gantry-travel axis, Y =
short/carriage axis). None of those files are being rewritten to swap
their letters; when reading any of them for physical/mechanical facts,
**swap X and Y mentally**. Only the physical facts (which member is
shaft-driven, which is 1200mm, which one carries the K40) are still
authoritative in those files — their letter labels are not, as of this
ADR.

Going forward, all new ADRs, hardware files, and BOM entries use Ortur's
convention (Y = short/dual-motor/rail axis, X = long/single-motor/
carriage axis) directly, no swap needed.

## Consequences

- Removes the mismatch risk between this project's documentation and the
  physically reused Ortur controller/firmware/wiring — the single
  biggest reason for this change.
- Real ongoing risk: 18 prior ADRs now require a mental swap to read
  correctly. [0014](0014-axis-naming-convention.md)'s own history shows
  this exact kind of X/Y mixup has bitten this project twice before —
  treat every future reference to "X" or "Y" from an ADR dated before
  2026-07-29 with active suspicion until cross-checked against this
  table.
- Wiring: when the reused Ortur harness is physically connected, its
  connectors/labels are the ground truth — match this project's new
  convention (Y = short axis) to whatever the harness's own connector
  labeling says, not to any pre-existing project document.
- **Real mechanical reversal from [0014](0014-axis-naming-convention.md)'s
  original reasoning**: 0014 deliberately kept the moving beam short
  (800mm) and put the guide rails on the long (1200mm) axis specifically
  to minimize the beam's moving mass/inertia. This machine's actual,
  already-proven geometry is the opposite — the beam is the long member
  (1200mm), carrying the carriage/K40 across the full span, while the
  rails (dual-motor axis) are only 800mm. Not a problem to fix — the
  Ortur has already been cutting at this exact geometry — just a real
  difference from the original design rationale, worth remembering if
  any old ADR's stiffness/deflection reasoning is ever revisited.
- No BOM changes — this is a naming/documentation change only, no parts
  added or removed.

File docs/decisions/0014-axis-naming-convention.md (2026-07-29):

# 0014. Axis naming and gantry topology: X = 1200mm guide rails, Y = 800mm beam

Date: 2026-07-13
Status: Superseded by [0043](0043-adopt-ortur-axis-convention.md) (topology changed 2026-07-13 — see note below; supersedes all
earlier versions of this ADR)

## Context

This ADR has been revised twice already (see the correction note at the
bottom for that history). This revision is different: it's not a bugfix,
it's a genuine topology decision.

**The topology**: "gantry" means the whole moving assembly — the beam plus
the carriage that rides on it. Two ways to arrange it on the 800mm x 1200mm
frame ([0009](0009-frame-dimensions-final.md)):

- **Guide rails on the short (800mm) sides, beam spans the long (1200mm)
  gap.** The guide rails carry the heaviest load (the whole gantry
  assembly), so keeping them short minimizes their deflection under that
  traveling load (deflection scales with span³). Tradeoff: the beam itself
  has to be long (1200mm) to span the gap, adding moving mass/inertia.
- **Guide rails on the long (1200mm) sides, beam spans the short (800mm)
  gap.** The beam — the thing that actually accelerates back and forth —
  stays light and short. The stationary frame can be as heavy/rigid as
  needed for free, since it never moves. Tradeoff: the guide rails, now
  spanning 1200mm instead of 800mm, deflect more under the traveling load.

Quantifying that tradeoff: extending the guide-rail span from 800mm to
1200mm increases worst-case deflection (simply-supported, concentrated
load, midspan) from roughly 0.02-0.05mm to roughly **0.12-0.18mm** — still
well under laser kerf width (0.1-0.3mm) and plywood's own thickness
variance, so not a functional problem, just less margin.

**Decision driver**: minimizing the moving gantry's mass/inertia (lighter,
more responsive motion, less strain on motors and belts, less
vibration/overshoot at speed) was judged more valuable than the extra rail
deflection margin, given the deflection at either span size is small enough
not to matter practically. The stationary frame's weight is free — "not
concerned about curb weight" for parts that don't move.

## Decision

- **X-axis = the long axis (1200mm).** Two guide rails
  ([0007](0007-frame-footprint-constraints.md)/[0009](0009-frame-dimensions-final.md)),
  fixed to the frame, MGN12-mounted. The **whole gantry** (800mm beam +
  carriage) travels along these, driven by **dual motors**
  ([0011](0011-x-axis-dual-motor.md)) since two rails must stay
  synchronized.
- **Y-axis = the fixed 800mm axis.** A single MGN12 rail mounted on the
  gantry beam itself. The **laser carriage** travels along it, driven by a
  single motor.

This deliberately diverges from Ortur's own number convention (their
kit extends what they call "Y" to reach 800mm) — that fact was true of
*their* internal architecture, not a binding constraint on ours. Our
machine's internal topology is a free choice within the shared 800x1200mm
outer footprint; we're using X/Y here per the role each axis plays in this
build (X = whole-assembly travel, matching the letter used when this
topology was first proposed in conversation), not to match Ortur's
firmware settings.

## Consequences

- [0008](0008-motion-system-mgn12-rails.md), [0011](0011-x-axis-dual-motor.md)
  (renamed back from "y-axis"), and [0015](0015-x-axis-motor-system.md)
  (renamed back from "y-axis") all updated to match: dual motors and the
  two guide rails are **X** (1200mm); the gantry beam's single rail and
  carriage are **Y** (800mm).
- [0016](0016-gantry-end-plate-rework.md) updated: the end plate connects
  the Y-axis beam to the carriage riding the X-axis guide rails (previously
  documented the other way around).
- [0016](0016-gantry-end-plate-rework.md)'s plate also gets an explicit
  orientation note: the guide rail extrusion is mounted wide-face-vertical
  (per the earlier rigidity decision, using the stronger Ix bending axis),
  so the carriage's usable mounting face is vertical/side-facing in the
  final assembly, not horizontal — the plate's 2D shape doesn't change, but
  it's installed rotated 90° from a "flat shelf" orientation. This wasn't
  documented explicitly before, which caused confusion.
- This is the final settled topology and naming for this build. Future
  ADRs should build on this without re-deriving it.

## Correction history (earlier versions of this ADR)

1. First version: X = long axis (whole-gantry travel), Y = 800mm (carriage
   axis) — based on the user's initial description, before checking Ortur's
   real convention.
2. Second version: flipped to Y = 800mm (whole-gantry-travel, guide rails,
   matching Ortur's `$131` kit behavior), X = long axis (carriage/beam
   span) — corrected after research into Ortur's Y-extension kit, but this
   revision *also* had the mechanical roles backwards relative to what was
   intended (conflated "which letter is 800mm" with "which member plays
   which role").
3. Third version (this one): topology itself changed — guide rails moved
   to the long 1200mm axis for mass/inertia reasons, beam is the short
   800mm member. Axis letters reassigned accordingly (X = 1200mm guide
   rails/whole-gantry travel, Y = 800mm beam/carriage travel) — back to the
   same letters as version 1, now for a deliberate, reasoned topology
   choice rather than by default.

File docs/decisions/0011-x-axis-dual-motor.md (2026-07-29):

# 0011. X-axis: dual independently-driven steppers, synced in firmware

Date: 2026-07-13
Status: Superseded by [0041](0041-ortur-electronics-reuse.md) (topology finalized 2026-07-13, see [0014](0014-axis-naming-convention.md))

## Context

The whole gantry (800mm beam + Y-rail + carriage) travels along the long
1200mm axis on two parallel MGN12 rails ([0008](0008-motion-system-mgn12-rails.md)),
one per side, and needs to stay synchronized so the gantry doesn't rack out
of square. Per [0014](0014-axis-naming-convention.md), this is the
**X**-axis — the guide rails were deliberately placed on the long axis
(rather than the fixed 800mm axis) to keep the gantry beam itself short and
light, minimizing the moving assembly's mass/inertia. The stationary
frame's own weight doesn't matter, since it never moves.

Two approaches were considered for keeping the two rails synchronized:

- **Single motor + mechanical link** (shaft or belt connecting both sides to
  one stepper): simpler electronically, but relies on a rigid mechanical
  coupling across the 1200mm span, which adds its own alignment/backlash
  concerns and puts the full load on one motor.
- **Dual independently-driven steppers**, one per side, each with its own
  driver, synchronized electronically (moved as a mirrored pair in
  firmware/controller config): more torque available across the gantry, no
  mechanical coupling shaft to keep aligned, and better suited to a heavier
  gantry load.

We're currently building around the K40 (~900g, [0002](0002-laser-module-selection.md)),
but there's a real possibility of moving to a substantially heavier module
later (up to ~1.4lb/~635g+ class, i.e. beyond the K40). Dual motors give
headroom for that without redesigning the X-axis drive. This is also the
heaviest-loaded pair of rails in the machine (they carry the whole gantry,
including the Y-axis's own rail/carriage/motor) — putting dual motors here
gives enough torque margin to move that load smoothly even though the span
is longer (1200mm) than the beam it's carrying (800mm). The resulting
deflection at this span (~0.12-0.18mm estimated, see
[0014](0014-axis-naming-convention.md)) remains well under laser kerf
width, so the mass/inertia benefit of a short beam wasn't traded against a
meaningful accuracy cost.

## Decision

Use **two independently-driven NEMA17 steppers on the X-axis**, one per
rail, synchronized in firmware (mirrored X/X2 axis config) rather than a
single motor with a mechanical coupling shaft.

## Consequences

- More torque available for the X-axis as a whole, and headroom for a
  heavier laser module later without changing the drive approach.
- No mechanical shaft/coupling to keep aligned across the 1200mm span —
  removes that failure/misalignment mode entirely.
- Requires a controller board with a dual-X (or X + mirrored A-axis) driver
  configuration — this becomes a requirement for the controller board
  selection (still an open decision).
- Both motors need to be homed/squared correctly (typically via dual limit
  switches, one per side) so the gantry doesn't rack out of square over
  time — an explicit homing/squaring step in the electrical/firmware design,
  not just physical assembly.

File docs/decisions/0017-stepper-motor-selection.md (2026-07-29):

# 0017. Stepper motor: STEPPERONLINE NEMA17, 59Ncm

Date: 2026-07-13
Status: Superseded by [0041](0041-ortur-electronics-reuse.md)

## Context

X-axis (dual motor, [0011](0011-x-axis-dual-motor.md)) and Y-axis (single
motor) both need NEMA17 steppers per the motor system design
([0015](0015-x-axis-motor-system.md)). Needed: standard NEMA17 body (fits
the off-the-shelf motor mounts), 5mm D-shaft (standard GT2 pulley bore),
enough torque for a belt-driven gantry axis at our load, from a reliable/
well-documented source.

## Decision

**STEPPERONLINE NEMA17 Bipolar, 59Ncm (84oz·in) holding torque, 2A, 48mm
body, 4-lead with 1m cable + connector.**
https://www.amazon.com/STEPPERONLINE-Stepper-Bipolar-Connector-compatible/dp/B00PNEQKC0

59Ncm gives real margin over what a belt-driven axis needs at this load
(not just barely adequate) — matches the pattern of choosing headroom over
minimum-spec throughout this build. STEPPERONLINE is a widely-used,
well-documented brand for this exact application (Voron/RepRap/OpenBuilds
builds), and the motor ships with a pre-terminated cable, reducing wiring
work.

**Quantity: 3** — 2 for X-axis (dual motor), 1 for Y-axis (single motor).
A 5-pack may be worth buying instead for spares / a head start on the
carriage-axis motor deferred earlier in this build.

Category: off-the-shelf.

## Consequences

- Motor mount brackets and pulleys ([0015](0015-x-axis-motor-system.md))
  need to match this motor's standard NEMA17 mounting pattern (31x31mm
  screw holes, ~22mm shaft boss) and 5mm shaft — standard, no compatibility
  risk expected.
- 48mm body length is slightly longer than the cheapest NEMA17 variants
  (typically ~34-40mm) — worth double-checking clearance in the motor mount
  area once that bracket is finalized.
- Driver/controller board selection (still open) needs to handle up to 2A
  per phase for this motor.

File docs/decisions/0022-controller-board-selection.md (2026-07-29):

# 0022. Controller board: grblHAL Teensy 4.1 T41U5XBB

Date: 2026-07-13
Status: Superseded by [0041](0041-ortur-electronics-reuse.md)

## Context

Needed: a controller supporting dual independently-driven X motors with
auto-squaring ([0011](0011-x-axis-dual-motor.md)), a single Y motor, laser
PWM output for the K40 ([0002](0002-laser-module-selection.md)), and
reliable LightBurn/LaserGRBL compatibility.

Three options were compared:

- **MKS DLC32 + FluidNC**: cheap (~$40-60), laser-purpose-built PWM output,
  dual-X via a documented but non-native Z-driver-slot remap. Real risk
  found in research: FluidNC replaced GRBL's classic `$$` settings system
  with its own YAML config, causing reported LightBurn 1.1+ connection
  failures and incomplete M4 (dynamic laser power) support in LaserGRBL.
- **BlackBox X32**: $239.99, turnkey (no soldering), native grblHAL, 4
  genuinely independent drivers (no remap needed), explicit LightBurn
  support. Removes all the risk points found above, at a real cost premium.
- **grblHAL Teensy 4.1 breakout board (T41U5XBB)**: native grblHAL (same
  protocol-fidelity benefit as BlackBox X32), explicitly lists "Moving
  gantry, Auto-squaring" as a supported configuration in its own
  documentation — directly matches our use case. 5-axis capacity. Requires
  soldering (connectors + Ethernet components) and a separately-purchased
  Teensy 4.1. Total cost ~$88.94 (board $47.99 + pre-configured Teensy 4.1
  $40.95) — well under the BlackBox X32, in exchange for assembly labor.

Given confirmed comfort with soldering, the Teensy 4.1 route gets the same
native-grblHAL compatibility and explicitly-supported auto-squaring
capability as the BlackBox X32, at roughly a third of the cost.

## Decision

**grblHAL Teensy 4.1 T41U5XBB breakout board** —
https://brookwood-design-77.myshopify.com/products/t41u5xbb-board-kit
— paired with a pre-configured Teensy 4.1 —
https://protosupplies.com/product/teensy41-cnc/

Total: $47.99 + $40.95 = ~$88.94.

Category: off-the-shelf (purchased kit requiring customer soldering
assembly, not custom-designed/machined).

## Consequences

- Soldering required: connectors and Ethernet components must be soldered
  by hand — real assembly time/skill requirement, accepted given confirmed
  comfort with soldering.
- 5-axis capacity leaves headroom for a future Z-axis or rotary attachment
  without a board change.
- Native grblHAL avoids the FluidNC compatibility risks found in research
  (LightBurn 1.1+ connection issues, incomplete M4 dynamic laser power
  support) — should give more reliable LightBurn/LaserGRBL operation.
- Exact laser PWM voltage/spec not confirmed from the product page (laser
  use is listed as a supported application, but detailed spec wasn't
  shown) — worth confirming once the board is in hand, before wiring the
  K40's TTL/PWM input.
- Auto-squaring configuration for the dual-X motors ([0011](0011-x-axis-dual-motor.md))
  still needs to be set up in grblHAL's settings once the board is
  assembled and wired — not yet done, tracked as follow-on work.

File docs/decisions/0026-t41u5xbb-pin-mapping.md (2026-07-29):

# 0026. T41U5XBB pin/header mapping

Date: 2026-07-14
Status: Superseded by [0041](0041-ortur-electronics-reuse.md)

## Context

The T41U5XBB's screw terminals are grouped and labeled by function on the
board's silkscreen (per its v2.07 manual), rather than numbered generically:

- **Stepper motor outputs**: one 4-pin group (G/Stp/Dir/En) per axis — X,
  Y, Z, A, B. 5V signals.
- **Limit switch inputs**: one per axis (X, Y, Z, A, B). Opto-isolated, 5V.
- **Control inputs**: Halt/Stop, Door, Feed/Hold, Cycle/Start. Opto-isolated, 5V.
- **Probe input**: opto-isolated, 5V.
- **Spindle group** (output): PWM, Direction, Enable, Ground — 5V TTL. Plus
  a separate 0-10V analog output (needs a 12V+ external feed to the
  amplifier if used).
- **Relay groups** (output): Flood, Mist, Spindle, Vac/Dust Collector, Aux0,
  Aux1, Aux2 — available as both direct relay-coil-driving outputs and 5V
  TTL (SSR-compatible) outputs.
- **Digital input**: 4 general-purpose Schmitt-triggered pins (St0-St3).
- **I2C header**, **Vac/DC trigger** input, **12V** and **5V** power
  terminals.

This machine only needs 3 real stepper motors — X1, X2 (ganged, per
[0011](0011-x-axis-dual-motor.md)'s "X + mirrored A-axis" plan), and Y —
plus the K40's control signal and the E-stop's Halt input
([0024](0024-e-stop-wiring.md)). Everything else on the board is either
reserved for future use or unused for now.

Confirmed from grblHAL's own community docs: the ganged second motor of an
auto-squared axis is wired to whichever axis letter is otherwise unused,
with $ settings (not decided in this ADR — tracked separately, see
Consequences) telling grblHAL to treat it as a mirrored partner rather than
an independent axis. The common convention (and what [0011](0011-x-axis-dual-motor.md)
already anticipated) is to use the **A** axis for this, keeping Z and B
free.

## Decision

Physical wiring assignment for this machine:

| T41U5XBB terminal group | Wired to | Notes |
|---|---|---|
| X stepper + X limit | X1 motor (one gantry rail side) | primary X reference |
| A stepper + A limit | X2 motor (other gantry rail side) | ganged/auto-square partner, per [0011](0011-x-axis-dual-motor.md) |
| Y stepper + Y limit | Y motor | single motor, [0021](0021-y-axis-motor-system.md) |
| Z stepper + Z limit | **unpopulated** | reserved for a future Z-axis/focus motor, per [0022](0022-controller-board-selection.md)'s 5-axis headroom note |
| B stepper + B limit | **unpopulated** | reserved for a future rotary attachment |
| Halt (control input) | **unpopulated** | E-stop hardware removed 2026-07-29 ([0024](0024-e-stop-wiring.md)) — the board's own manual recommends not leaving this disabled/unwired, but no physical Halt button exists in this design; the switched power strip is the emergency stop instead |
| Door (control input) | jumper (no Safety Door sensor) | per [0024](0024-e-stop-wiring.md)'s follow-on note |
| Feed/Hold, Cycle/Start | **unpopulated** | no pendant/control panel decided yet |
| Probe | **unpopulated** | no touch probe on a laser |
| Spindle group: PWM | K40 TTL/PWM cable, yellow wire | confirmed 5V TTL match, [0024](0024-e-stop-wiring.md) |
| Spindle group: Ground | K40 TTL/PWM cable, black wire | |
| Spindle group: Direction, Enable | **unpopulated** | K40 doesn't use these |
| 0-10V output | **unpopulated** | K40 uses PWM/TTL, not analog |
| Relay groups (Flood/Mist/Spindle/Vac-Dust/Aux0-2) | **unpopulated for now** | candidate for air-assist pump on/off control (M7/M8) later — not decided in this ADR |
| Digital input (St0-3), I2C, Vac/DC trigger | **unpopulated** | no current use |

Per the manual's own recommendation, all screw terminals will still be
soldered on during assembly even where unpopulated for now — retrofitting
them later is difficult due to their interlocking design.

## Consequences

- Confirms the physical wiring plan needed before assembly — no more
  guessing which screw terminal group a given wire goes to.
- Z and B axes are deliberately left free, preserving the 5-axis headroom
  [0022](0022-controller-board-selection.md) called out for a future
  Z-focus motor or rotary attachment.
- Does **not** decide the grblHAL `$` settings needed to actually configure
  A as X2's ganged/auto-square partner (motor ganging bitmask,
  auto-square-enable bitmask, squaring-travel limit) — that's the
  already-tracked follow-on work from [0022](0022-controller-board-selection.md)
  ("auto-squaring configuration... still needs to be set up").
- The Spindle group's Direction and Enable outputs, and all Relay outputs,
  are free — worth revisiting when the air-assist pump ([0004](0004-air-assist-pump.md)/[0005](0005-air-assist-pump-update.md))
  gets wired, since it's currently just plugged into its own wall power
  with no on/off tied to the laser firing.
- Feed Hold / Cycle Start / Probe inputs are left unpopulated — if a
  physical control pendant or touch-probe is added later, wiring is
  straightforward (terminals are already present) but not designed here.

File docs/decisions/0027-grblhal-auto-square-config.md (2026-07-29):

# 0027. grblHAL auto-squaring configuration for the ganged X-axis

Date: 2026-07-14
Status: Superseded by [0041](0041-ortur-electronics-reuse.md)

## Context

[0011](0011-x-axis-dual-motor.md) calls for X1/X2 synced in firmware as a
mirrored pair, and [0026](0026-t41u5xbb-pin-mapping.md) wires X2 to the
board's **A** axis outputs/limit input. What was still missing: how
grblHAL is actually told to treat A as X's ganged partner rather than an
independent 4th axis.

Researched this directly against grblHAL's own source (`my_machine.h`
template, shared across grblHAL board families including the Teensy 4.x/
iMXRT1062 driver the T41U5XBB uses) and community discussion:

- **Ganging is a compile-time firmware choice**, not a runtime `$`
  setting. It's controlled by `#define`s in `my_machine.h`:
  ```
  #define X_GANGED       1
  #define X_AUTO_SQUARE  1
  ```
  This requires a board map that supports more than 3 motors — confirmed
  true for the T41U5XBB (5-axis capable, [0022](0022-controller-board-selection.md)).
- **Standard prebuilt binaries do not have this enabled.** The T41U5XBB's
  listed prebuilt options (`3 axis usb no opts`, `5 axis usb no opts`,
  etc.) are generic axis-count builds — none of them pre-enable X-ganging.
  Getting X_GANGED/X_AUTO_SQUARE requires either using grblHAL's web
  builder with these options checked, or compiling
  [phil-barrett/grblHAL-teensy-4.x](https://github.com/phil-barrett/grblHAL-teensy-4.x)
  from source with a modified `my_machine.h`.
- A related option, `X_GANGED_LIM_MAX`, would make A's limit input act as
  a *max*-travel switch instead. We don't want that: per
  [0011](0011-x-axis-dual-motor.md)'s squaring approach, A's limit switch
  needs to independently detect its own side's min-travel homing trigger
  (that's the whole point of auto-squaring — each side homes to its own
  switch, and grblHAL corrects any skew between them). So this stays
  **unset**.
- Beyond the compile-time flags, several runtime `$` settings finish the
  configuration, but their actual values can't be responsibly picked until
  the machine is physically wired and can be homed at least once:
  - `$22` — Homing enable (must be `1`, prerequisite for squaring to run
    at all)
  - `$8` — Ganged Dir Invert Mask — whether X2's direction needs
    inverting depends on how the motor ends up physically wired/mounted,
    unknowable in advance
  - `$170` — Auto Square Offset for the X axis (fine pulloff trim to
    correct small residual skew) — this is a measured correction value,
    only meaningful after the gantry has actually been homed and checked
    for square
  - `$347` / `$348` / `$349` — Dual Axis Length Fail percent/min/max
    (how much skew is tolerated before grblHAL alarms instead of
    correcting) — reasonable defaults exist but the right value depends on
    the actual gantry's mechanical slop, not something to guess now

## Decision

- Build (or web-build) custom grblHAL firmware for the T41U5XBB with:
  ```
  #define X_GANGED       1
  #define X_AUTO_SQUARE  1
  ```
  and `X_GANGED_LIM_MAX` left disabled, so A's limit switch acts as X2's
  own min-travel/squaring reference switch rather than a max-travel
  switch.
- Defer setting `$8`, `$170`, `$347`, `$348`, `$349` to first commissioning
  (after the gantry is wired and can be jogged/homed) rather than guessing
  values now. `$22=1` can and should be set as soon as the firmware is
  flashed, since it's a prerequisite with no ambiguity.

Category: firmware/software configuration, not a physical part — no BOM
impact.

## Consequences

- Closes the compile-time half of this open item — there's now a concrete
  firmware build target instead of an open question.
- The board can no longer just use an off-the-shelf prebuilt binary;
  whoever flashes it needs to either use grblHAL's web builder with these
  options selected, or build from source. Worth doing this as one of the
  first steps once the board arrives, since re-flashing later after wiring
  is still easy but best not deferred indefinitely.
- The runtime `$` tuning ($8, $170, $347-349) is explicitly a
  commissioning-time task, not something resolved by this ADR — tracked as
  follow-on work, same pattern as [0016](0016-gantry-end-plate-rework.md)'s
  "must be checked against actual hardware" items.
- If a Z-axis or rotary attachment is added later ([0022](0022-controller-board-selection.md)'s
  headroom note), the firmware will need X_GANGED/X_AUTO_SQUARE preserved
  across any rebuild that also enables those axes.

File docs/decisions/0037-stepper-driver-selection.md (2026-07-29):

# 0037. Stepper driver modules: STEPPERONLINE DM542T

Date: 2026-07-15
Status: Superseded by [0041](0041-ortur-electronics-reuse.md)

## Context

Found while building the wiring diagram ([docs/reference/wiring-diagram.svg](../reference/wiring-diagram.svg)):
no ADR had ever selected actual stepper driver modules. [0017](0017-stepper-motor-selection.md)
picked the motors themselves, and [0022](0022-controller-board-selection.md)'s
T41U5XBB manual confirms its stepper outputs are **5V logic step/dir/enable
signals only** ("capable of driving opto-isolated stepper driver inputs"),
routed via screw terminals or pin headers — not integrated driver ICs, and
not a pluggable-stepstick socket either. The board genuinely cannot drive
motor coils on its own; external driver modules were a missing piece of
the BOM.

**STEPPERONLINE DM542T** — same brand as the motors ([0017](0017-stepper-motor-selection.md)),
and unlike a lot of generic hardware in this build, this one has an actual
manufacturer datasheet with a real pinout (not a guessed/aggregated
estimate):

- **Control connector (P1)**: 3 opto-isolated inputs — PUL+/PUL-,
  DIR+/DIR-, ENA+/ENA-. Accepts single-ended or differential signals,
  which covers the T41U5XBB's single-ended 5V logic step/dir/enable
  outputs directly (signal to the `+` pin, common ground to the `-` pin).
- **Power/motor connector (P2)**: 20-50VDC power input (comfortably covers
  the 24V main rail, [0023](0023-power-supply-selection.md)), A+/A-/B+/B-
  motor phase outputs.
- **Current setting**: DIP-switch selectable, 1.0-4.2A range — covers the
  motor's 2A/phase rating ([0017](0017-stepper-motor-selection.md)) with
  margin, adjustable without needing UART/SPI configuration.
- Widely used, well-documented in the CNC/DIY community for exactly this
  external-breakout-plus-standalone-driver topology.

## Decision

**3x [STEPPERONLINE DM542T](https://www.amazon.com/STEPPERONLINE-1-0-4-2A-20-50VDC-Micro-step-Resolutions/dp/B06Y5VPSFN)**
(1.0-4.2A, 20-50VDC digital stepper driver) — one per motor (X1, X2/A, Y,
per [0011](0011-x-axis-dual-motor.md)/[0021](0021-y-axis-motor-system.md)).

Wiring: T41U5XBB's X/A/Y step/dir/enable outputs → each driver's PUL+/DIR+/ENA+
(with the corresponding `-` pins tied to the controller's signal ground).
Main rail fuse block's X1/X2/Y branches (3A each, 18AWG, [0025](0025-24v-rail-fusing.md)/[0030](0030-24v-wire-gauge.md))
→ each driver's P2 24V power input. Driver's A+/A-/B+/B- → motor phase
leads.

Category: off-the-shelf ([0003](0003-parts-sourcing-constraint.md)).

## Consequences

- Closes the gap found while building the wiring diagram — the machine
  can now actually be wired end-to-end from controller to motor, where
  before there was a real hole in the BOM.
- Current DIP switches need setting to match the motor's 2A/phase rating
  at commissioning — not a design decision, a physical switch-flip once
  the driver is in hand (consistent with how other commissioning-time
  settings are handled, e.g. [0027](0027-grblhal-auto-square-config.md)).
- These are physically larger than stepstick-style modules (DM542T is a
  standalone boxed driver, not a small plug-in board) — needs its own
  mounting space in the electronics enclosure, not accounted for
  elsewhere yet.
- [docs/reference/wiring-diagram.svg](../reference/wiring-diagram.svg)
  updated to replace the flagged gap with this actual product.

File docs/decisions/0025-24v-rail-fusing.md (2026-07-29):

# 0025. 24V rail fusing: blade fuse distribution blocks, per-branch

Date: 2026-07-14
Status: Accepted

## Context

Two independent 24V DC rails exist on this machine ([0023](0023-power-supply-selection.md),
[0024](0024-e-stop-wiring.md)):

- **Main rail** (Mean Well LRS-350-24, 350W/14.6A max): powers the 3
  NEMA17 steppers ([0017](0017-stepper-motor-selection.md)) and the
  T41U5XBB controller board ([0022](0022-controller-board-selection.md)).
  Calculated worst-case load ~154W (~6.4A), well under the supply's rating.
- **K40 rail** (the module's own dedicated 24V/8A adapter, unrelated to
  the main rail): powers the laser diode driver. Originally gated through
  an E-stop relay; that hardware was removed 2026-07-29
  ([0024](0024-e-stop-wiring.md)) — this rail now runs adapter-to-module
  directly, with only the fuse below in line, no relay.

Neither rail has had its branch wiring protected yet — flagged as
follow-on work in both 0023 and 0024. General DC-CNC wiring practice:
fuse the main supply output at ~125-150% of calculated load, then fuse
each downstream branch individually so a fault in one stepper/driver or
in the laser wiring doesn't take down the whole rail or require guessing
which branch failed. Switch-mode supplies (like the LRS-350-24) are also
sensitive to being loaded past their rating by simultaneous peaky stepper
current draws, so keeping each branch's fault current contained matters
for supply stability, not just wiring safety.

## Decision

Automotive-style ATC/ATO blade fuse distribution blocks (cheap,
off-the-shelf, tool-free fuse replacement) on both rails:

**Main rail** (after the LRS-350-24, before branching):
- Main fuse: **10A** fast-blow (~150% of the ~6.4A calculated load)
- Branch: X1 stepper driver — **3A**
- Branch: X2 stepper driver — **3A**
- Branch: Y stepper driver — **3A**
- Branch: controller board (T41U5XBB + limit switches/logic) — **2A**

**K40 rail** (between the adapter and the E-stop relay from [0024](0024-e-stop-wiring.md)):
- Branch: K40 module main power — **10A** (~125% of the module's 8A rated
  draw)

Category: off-the-shelf.

## Consequences

- A fault isolated to one stepper branch, the controller branch, or the
  K40 branch blows only that branch's fuse — the rest of the machine stays
  live and the failed branch is immediately identifiable by which fuse
  tripped, rather than the whole rail dropping.
- The 10A main-rail fuse sits well under the LRS-350-24's 14.6A max output,
  so normal operation (including simultaneous multi-axis moves) shouldn't
  nuisance-trip it.
- Wire gauge for each branch needs to be sized to its fuse rating (not yet
  specified here) — worth confirming against whatever gauge wire is
  actually sourced, so the fuse is protecting wire that can actually carry
  its rated current without overheating first.
- Two separate fuse blocks are needed (one per rail) since the rails don't
  share a common ground/return — consistent with [0023](0023-power-supply-selection.md)'s
  decision to keep the K40's power independent rather than folding it into
  the main rail.

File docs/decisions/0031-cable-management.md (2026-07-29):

# 0031. Cable/tubing management: spiral wrap + tensioned support, no drag chain

Date: 2026-07-14
Status: Accepted (tensioning mechanism superseded 2026-07-22 — see update
below; spiral wrap and the no-drag-chain approach still stand)

## Context

Two moving joints need flexible cable/tubing runs that were previously
undesigned (flagged in the 2026-07-14 repo review): the **X-axis** run
(fixed frame → moving gantry beam, carrying the Y-motor's leads, the Y
limit switch's leads, and everything continuing on to the Y-carriage) and
the **Y-axis** run (a fixed point on the beam → the moving Y-carriage,
carrying the K40's power/PWM cable and the air-assist tubing).

Rather than a rigid drag chain (the usual CNC/3D-printer default — a
plastic link-chain track that encloses and guides the cable through a
fixed bend radius), the choice here is a lighter-weight approach modeled
on ceiling-pulley VR headset cable management systems: those keep a
headset cable off the floor and out of the user's way using a retractable/
elastic overhead line that takes up slack as the user moves, rather than a
rigid track.

## Decision

For both the X-axis and Y-axis cable runs:

- **Spiral wrap** (spiral cable wrap sleeving) bundles the relevant wires/
  tubing for each run into a single manageable, abrasion-protected bundle
  — same approach at both stages, just different bundle contents (X-level:
  Y-motor leads + Y-limit-switch leads + everything passing through to the
  Y-carriage; Y-level: K40 power/PWM cable + air-assist tubing).
- **Tensioned support**, VR-headset-style: rather than a rigid drag chain
  track, the bundle is held with light elastic/spring tension along its
  run (e.g., an elastic cord or light spring in parallel with the bundle,
  anchored at both ends) so slack is taken up automatically as the gantry/
  carriage moves, without the bundle dragging, sagging into moving parts,
  or resisting motion the way a poorly-tensioned drag chain can.

**Update (2026-07-22)**: the elastic-cord-along-the-frame tensioning
mechanism above is superseded — the user already owns a **ceiling-suspended
VR headset cable management system** (the actual real-world equivalent of
the analogy this ADR was originally modeled on) and will route the
spiral-wrapped bundle up to that instead of tensioning it along the frame.
This removes the need for frame/beam/carriage-mounted elastic cord and
anchor points entirely — slack management happens overhead, external to
the machine, via hardware already on hand. Spiral wrap still bundles the
wires/tubing at each moving joint the same as before; only the
slack-take-up mechanism changes. The Y-carriage still likely needs a
single simple clip/loop point where the bundle connects to the overhead
minder's line — much lighter-weight than the original tensioned-anchor
design, not separately tracked here.

Category: off-the-shelf consumables (spiral wrap) — no custom part needed
for the wrap itself; slack management is external (ceiling-mounted VR
cable minder, already owned).

## Consequences

- Removes the drag-chain design/routing problem entirely — no chain
  track, no chain link pitch/radius to size, no chain-mount brackets to
  design at either end.
- **(Superseded 2026-07-22)** ~~Anchor points for the tension line and
  bundle need to exist on: the fixed frame, the gantry beam, and the
  Y-carriage~~ — no longer needed now that slack is managed by the
  ceiling-mounted VR cable minder instead of a frame-tensioned line. Only
  a single simple clip/loop point on the moving carriage (where the
  bundle connects up to the overhead minder) remains, not a full anchor
  system at three points.
- Because there's no rigid track constraining bend radius, care is needed
  at assembly to keep the spiral-wrap bundle's actual bend radius
  comfortable at both ends of travel (especially the K40's power/PWM
  cable, which is less flexible than the air-assist tubing) — a
  commissioning-time check, not a design decision to pre-calculate here.
  Still applies with the ceiling-suspended approach.
- **(Superseded 2026-07-22)** ~~Tension needs to be light enough not to
  meaningfully load the stepper motors... worth verifying/tuning once
  physically assembled~~ — this tuning concern belongs to the VR cable
  minder hardware itself now (already-owned, presumably already tuned for
  its intended use), not something to design/verify here.

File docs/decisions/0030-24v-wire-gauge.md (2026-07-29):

# 0030. Wire gauge per 24V fuse branch

Date: 2026-07-14
Status: Accepted

## Context

[0025](0025-24v-rail-fusing.md) set fuse ratings for both 24V rails but
left wire gauge open — a fuse only protects wire that's actually rated to
carry its current; undersized wire can overheat before a fuse ever blows.

Using the standard chassis-wiring AWG ampacity table (short, ventilated
runs — the relevant column for wiring inside a machine frame, not bundled
power-transmission cable) as a baseline:

| AWG | Chassis ampacity |
|---|---|
| 24 | 3.5A |
| 22 | 7A |
| 20 | 11A |
| 18 | 16A |
| 16 | 22A |
| 14 | 32A |

Picking the bare-minimum gauge that clears each fuse rating (e.g. 24 AWG
for a 3A branch) would technically pass an ampacity check, but two things
push toward one size heavier than the minimum:

- **Screw-terminal robustness**: both the T41U5XBB's control/stepper
  terminals ([0026](0026-t41u5xbb-pin-mapping.md)) and the blade fuse
  blocks ([0025](0025-24v-rail-fusing.md)) are screw-clamp connections —
  thin wire (24-22 AWG) makes a weaker mechanical connection that's more
  prone to working loose under the vibration this machine generates during
  cutting moves.
- **The K40 branch flexes with the gantry**: unlike the X/Y stepper and
  idler wiring, which is fixed motor/frame-mounted and never moves
  ([0015](0015-x-axis-motor-system.md)), the K40 rides the X-carriage —
  its power leads need to survive continuous drag-chain flexing, which
  favors a slightly heavier, genuinely stranded (not solid-core) wire over
  the bare ampacity minimum.

## Decision

**Simplified to a single gauge for the whole machine (2026-07-22)**: originally
specified per-branch (16/18/20 AWG below), but standardizing on **16 AWG for
every branch** to make this a single purchase instead of three separate
spools — 16 AWG already clears the highest branch fuse (10A) with margin, so
running it on the lower-current 3A/2A branches too is just extra headroom,
not undersized wire anywhere.

| Branch | Fuse ([0025](0025-24v-rail-fusing.md)) | Wire gauge |
|---|---|---|
| Main rail: PSU output → fuse block | 10A main | **16 AWG** |
| X1 / X2 / Y stepper branches (each) | 3A | **16 AWG** (was 18 AWG) |
| Controller board branch | 2A | **16 AWG** (was 20 AWG) |
| K40 rail: adapter → E-stop relay → module | 10A | **16 AWG**, drag-chain-rated stranded |

Category: off-the-shelf wire/consumables, no BOM-defining product link
needed (standard hookup wire).

## Consequences

- Every branch's wire ampacity now clears its fuse rating with comfortable
  margin (roughly 1.5-2x headroom at chassis-wiring ratings on the 10A
  branches; substantially more on the 3A/2A branches now that they're also
  16 AWG), rather than sitting at the bare minimum.
- One spool size to buy instead of three — simpler purchasing, at the cost
  of slightly bulkier/stiffer wire than strictly necessary on the low-current
  stepper/controller branches. Not a functional downside, just a minor
  routing/bulk tradeoff accepted for purchasing simplicity.
- The K40 branch specifically should be sourced as flexible stranded wire
  rated for continuous flexing (e.g. drag-chain/robotic cable, not generic
  stranded hookup wire) given it moves with the gantry — this is a sourcing
  note, not a new part to design.
- Completes the electrical wiring plan started in [0023](0023-power-supply-selection.md)
  (PSU sizing) through [0025](0025-24v-rail-fusing.md) (fusing) — gauge was
  the last unresolved piece of that chain.
- Voltage drop wasn't separately calculated — at these currents and the
  short in-frame run lengths expected, the chassis-wiring ampacity margin
  already covers it, but worth a sanity check once actual cable run lengths
  are known at assembly.

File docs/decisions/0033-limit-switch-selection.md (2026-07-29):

# 0033. Limit switch selection and mounting

Date: 2026-07-14
Status: Accepted

## Context

[0026](0026-t41u5xbb-pin-mapping.md) wired the T41U5XBB's X, A, and Y limit
inputs (opto-isolated, 5V) but never picked a physical switch or mounting
method — flagged in the 2026-07-14 full-repo review. Three switches are
needed: **X** (X1's own min-travel switch), **A** (X2's ganged/auto-square
reference switch, [0027](0027-grblhal-auto-square-config.md)), and **Y**
(single switch on the beam).

**Switch type**: mechanical roller-lever microswitch — the standard,
well-proven choice for this application (vs. optical/hall-effect sensors,
which add cost/complexity this build doesn't need). The common KW12-3-style
SPDT microswitch (1NO + 1NC + common, 3-pin) is the de facto standard part
for this across the CNC/3D-printer hobby space.

**NC vs. NO wiring**: same reasoning already applied to the E-stop/control
inputs ([0024](0024-e-stop-wiring.md)) — NC is more EMI-resistant and a
broken wire reads as a fault (triggers homing to stop/alarm) rather than
silently failing to detect a real crash. Using the switch's NC contact for
all three, consistent electrical philosophy across the whole machine
rather than mixing NO and NC by input type.

**Exact switch dimensions**: same situation as the corner bracket
([0028](0028-corner-bracket-hardware-selection.md)) and the K40's mounting
plate ([0032](0032-y-axis-laser-carriage.md)) — checked multiple listings
and the Mouser-hosted datasheet PDF (fetch failed; connection reset) for
this common part family. Aggregated, reasonably-consistent figures across
sources: body ~20 x 10 x 6.5mm, two M2 mounting holes ~9-9.5mm apart,
roller lever ~18mm long. Designing the mount with slotted (not fixed)
holes to absorb that uncertainty, same approach as the other two.

## Decision

**Switch**: BOJACK (or equivalent KW12-3-style) SPDT micro limit switch,
1NO+1NC+common, 3-pin, roller lever arm — 10-pack (covers the 3 needed
with 7 spares, consistent with this build's usual spares-included
purchasing pattern). Wired using each switch's **NC** contact.

**Mounting (2026-07-22, material changed to black acrylic)**: originally
a PLA-CF printed L-bracket; switched to laser-cut black acrylic to match
the rest of the acrylic stock already being ordered
([0029](0029-laser-cut-material-selection.md)). This is a real geometry
change, not just a material swap: the current design is a single-piece
3D-printed L-bracket (two perpendicular legs), which doesn't translate
directly to a flat laser-cut part. Needs redesigning as either (a) two
flat acrylic pieces joined at 90° via slot-and-tab joinery (glued or
press-fit, same general idea as furniture-style laser-cut joints), or
(b) a flattened single-piece mounting scheme that doesn't need a bent
corner at all. **Not yet designed** — deferred the same way the switch's
own hole spacing already was, since both are waiting on the actual
switch being in hand to confirm dimensions before cutting. Original
PLA-CF geometry below describes the mounting concept (T-slot leg + switch
leg) that still needs re-expressing in acrylic-compatible form:

- **Mounting leg**: flat against the 2020/2040 extrusion face, with a
  vertical slot (not a fixed hole) for an M5 bolt + T-nut — lets the
  switch's position slide along the rail before tightening, so the exact
  trigger point can be fine-tuned at assembly rather than needing to be
  calculated in advance (same adjustment principle already used for idler
  belt tensioning, [0018](0018-motor-and-idler-mounts.md)).
- **Switch leg**: perpendicular to the mounting leg, with 2 slotted M2
  holes (working estimate 9.5mm spacing, generously slotted) for the
  switch body, oriented so the roller lever projects into the oncoming
  carriage/block's travel path.

Mounting locations: X and A switches at the corresponding (same-side) end
of each X guide rail on the fixed frame; Y switch at one end of the beam.

Category: off-the-shelf (switches) + laser-cut black acrylic (mount
bracket, [0003](0003-parts-sourcing-constraint.md), [0029](0029-laser-cut-material-selection.md)).

Superseded parametric model (PLA-CF, no longer built): [hardware/3d-printed/limit-switch-mount.scad](../../hardware/3d-printed/limit-switch-mount.scad),
kept for reference. No acrylic design file exists yet — pending switch
dimensions.
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

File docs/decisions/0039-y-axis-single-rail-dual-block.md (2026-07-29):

# 0039. Y-axis: single rail, two carriage blocks (reverts 0038's dual-rail/2060 upgrade)

Date: 2026-07-22

Status: Accepted (supersedes [0038](0038-y-axis-dual-rail.md) in full — beam
reverts to 2040 per [0010](0010-extrusion-profile-2040.md); the Y-axis
cantilever-moment concern that motivated 0038 is instead resolved by
mounting two carriage blocks on one rail)

## Context

A real-price check on MGN12 rail/block hardware (LiMo Bearing's own
configurator, confirmed prices, not estimates) found 0038's dual-rail
approach costs more than it needs to, and that switching brands (HGR15/
HGH15, considered as an alternative) doesn't help either:
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

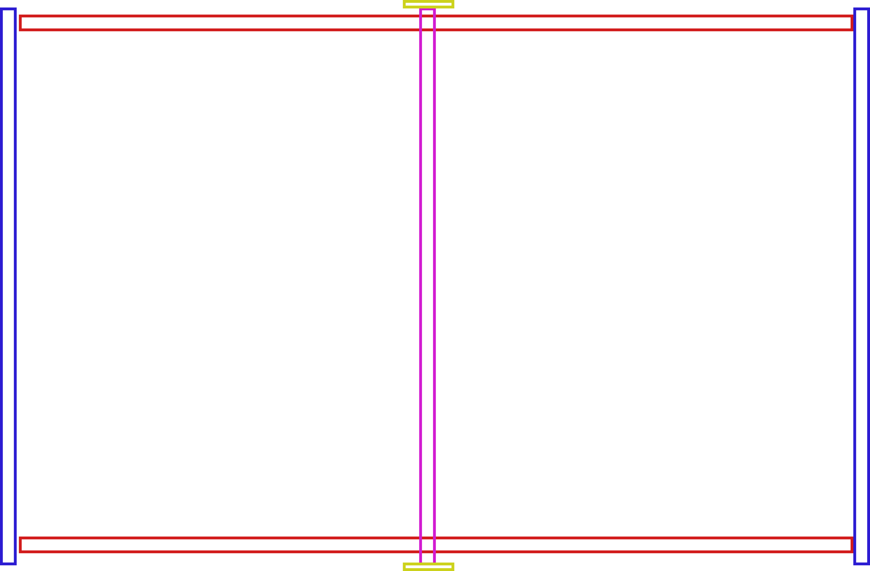
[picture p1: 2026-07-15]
docs/reference/frame-topology-sketch.png

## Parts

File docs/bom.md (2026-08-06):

# Bill of Materials

Consolidated shopping list, compiled from all ADRs in [docs/decisions/](decisions/).
Each line links back to the ADR that decided it — check there for context,
rationale, and any unresolved caveats (several items below are marked
**verify** and should not be treated as final until confirmed against
physical hardware).

**2026-08-06: machine built and running.** See
[Control system quick-reference](#control-system-quick-reference-if-the-controller-fails)
below for a short, standalone spares list scoped to just the
controller/power/laser-firing chain — the part most likely to need
emergency replacement, separate from the full BOM below.

**2026-07-29: pivoted to reusing the Ortur LM2 S2's own controller,
drivers, motors, wiring, and limit switches** instead of a new grblHAL
controller build ([0041](decisions/0041-ortur-electronics-reuse.md)).
The controller board, stepper drivers, and steppers below are no longer
being purchased — see "No longer needed" below. The full original
custom-controller BOM is preserved on the `custom-controller-fallback`
git branch.

## Control system quick-reference (if the controller fails)

Standalone list, scoped to just what's needed to get power, motion, and
laser-firing working again — not the frame/motion mechanicals. Pulled
from the full BOM below; check there and the linked ADRs if anything
here needs more context.

| Part | Notes |
|---|---|
| Ortur LM2 S2 mainboard (silkscreened `OLM-ESP-PRO_V1.2`) | Reused from the original Ortur, **not purchased new — no sourcing link on record.** If this board dies, a replacement isn't yet identified; check Ortur's own parts/support channel first, or an equivalent GRBL-based board (would need re-verifying pin mapping against the notes below). This is the one real gap in this list. |
| K40's bundled 24V/8A PSU | Sole power supply for the **entire machine** (controller + motors + laser) — not the Mean Well. Feeds the Ortur mainboard's 24V input. |
| Mean Well LRS-350-24 PSU (24V, 14.6A) | Purchased spare, not in the live power path. Swap in if the K40's PSU fails. |
| LaserTree K40 laser module | Fires via direct wiring, **not** through its bundled adapter board — see wiring below. |
| K40's bundled adapter board | **Not used.** Powered the module but never passed PWM through (isolated by testing both its power modes); kept as a spare part only, not part of the working signal path. |
| Direct-wire laser harness (custom) | The LU2-10A's own original cable — cut at the laser end and re-terminated to fit the K40's screw terminals. **The LU2-10A is no longer wired up**, but the original connector that was cut off is saved, so the LU2-10A can be restored by re-terminating it back on. Not a purchasable part — see pin map below to rebuild it. |
| 6-Way ATC/ATO fuse block + assortment | In hand — see [Electronics & power](#electronics--power) below for fusing notes |
| 110-120V AC panic-paddle E-stop switch | Wired ahead of the switched power strip, sole emergency shutoff ([0024](decisions/0024-e-stop-wiring.md)) |

**Ortur mainboard laser-output pin map** (from the board's own silkscreen —
see [Reference/d8804ccb4a881b6d5972ff01df58020ced912551.jpeg](../Reference/d8804ccb4a881b6d5972ff01df58020ced912551.jpeg)):

- `LA_PWM` — PWM signal (fluctuating-duty-cycle pin; reads as a DC
  average on a multimeter, not a visibly moving value — ~0V at 0% power,
  ~5V at 100%)
- `LA_PWR` — 24V, broken out on two adjacent pins (silkscreened `YA1`/
  `YB1`, repurposed since this build only uses one Y motor)
- Any silkscreened `GND` pin on the same header block (paired with
  `X_LIMIT`, `Y_LIMIT`, `YB2`, `YA2`, `FAN`, or `5V`) — **not** the pin
  labeled `FIRE`, which is a flame-sensor input, not ground

To rebuild the harness: this cable was the LU2-10A's own — its original
laser-end connector was cut off but **saved**, so the LU2-10A can be
restored by re-terminating that connector back on. If a fresh harness
is ever needed for a *different* module (not the LU2-10A), it'd need
to be made from scratch: an Ortur-side connector matching the
mainboard's laser-output socket, wired to the three pins above,
terminated at the laser end to fit whatever module's screw terminals.

## Purchased / in hand

- MGN12 linear rail + MGN12H carriage block (Y-axis) — bought 2026-07-22
- 2040 V-slot aluminum extrusion — bought 2026-07-22
- DiGiYes GT2 20T idler pulley (toothless/smooth) — bought 2026-07-22
- 1-Pack Assembled 2040 V Gantry Plate Kit — all 3 confirmed in hand (2026-07-22)
- 6mm GT2 timing belt — bought 2026-07-22
- Socobeta NEMA17 motor mount bracket — bought 2026-07-22
- Mean Well LRS-350-24 PSU — bought 2026-07-22
- 3DMAN GT2 belt clamp, 9x40mm — bought 2026-07-22
- BEMONOC GT2 20T drive pulley (toothed) — bought 2026-07-22
- Inside Hidden Corner Bracket, 90°, M5, 20-series — bought 2026-07-22
- AquaMiracle air pump — bought 2026-07-22
- M8 swivel leveling feet — bought 2026-07-22
- Caster wheel connector, 2020-series, M8 tapped — bought 2026-07-22
- Black acrylic sheet stock — bought 2026-07-22
- Silicone air tubing — already had on hand
- Assorted M3/M5 screws, washers, T-nuts — already had, leftover from a previous build
- Zip ties — already had
- Cable clips — in hand (2026-07-29)
- Spiral cable wrap sleeving — in hand (2026-07-29)
- 6-Way ATC/ATO blade fuse block (both, main rail + K40 rail) — in hand (2026-07-29)
- ATC/ATO fuse assortment, 1A-40A full range — in hand (2026-07-29), closes the gap the fuse block kit's own included set didn't cover (3A/2A)
- Switched power strip — already had on hand
- 110-120V AC panic-paddle safety switch (table saw/milling machine style, large red stop-sign paddle) — in hand (2026-07-29), wired ahead of the power strip as the sole emergency shutoff, [0024](decisions/0024-e-stop-wiring.md)

**Not part of this design** ([0041](decisions/0041-ortur-electronics-reuse.md), 2026-07-29
electronics-reuse pivot): grblHAL T41U5XBB breakout board, Teensy 4.1,
STEPPERONLINE NEMA17 steppers, STEPPERONLINE DM542T drivers, 16 AWG
stranded silicone wire, KW12-3-style SPDT microswitches — this design
reuses the Ortur LM2 S2's own controller, drivers, motors, wiring, and
limit switches instead. (Also **no longer needed**, from the earlier
2026-07-29 E-stop rework, [0024](decisions/0024-e-stop-wiring.md)): 22mm
mushroom E-stop switch, 24VDC SPDT relay.

**LaserTree K40 laser module — in hand and firing (2026-08-06).** Briefly
switched to the K30 ([0044](decisions/0044-laser-module-k30.md)), reverted
back to K40 ([0045](decisions/0045-revert-to-k40.md)) for the power
headroom before ordering. **The K40's bundled LaserTree adapter board is
not part of the final wiring path** — it powered up but never passed a
PWM signal to the module (adapter fault, isolated by testing both its
internal/external power modes with the same result). Fixed by direct-wiring: LA_PWM,
LA_PWR (24V), and a GND pin from the Ortur mainboard's own laser-output
header, using the LU2-10A's own original cable — cut and re-terminated to
fit the K40's screw terminals (the LU2-10A now has nothing plugged into
it), bypassing the adapter entirely. See the
[control system quick-reference](#control-system-quick-reference-if-the-controller-fails)
below for the exact pin map.

**Power supply: running off the K40's bundled 24V/8A PSU, not the Mean
Well LRS-350-24.** The K40's own supply now powers the entire
machine — controller, motors, and laser — through the Ortur mainboard's
24V input. The Mean Well LRS-350-24 (below, purchased 2026-07-22) is not
in the live power path; keep it as a spare/backup rather than a required
part.

Everything else in this BOM is in hand.

## Structural (frame)

| Part | Qty | Source / link | ADR |
|---|---|---|---|
| 2040 V-slot aluminum extrusion, cut to length: 2x 1200mm (frame long sides, rails mount outside face), 2x 800mm (frame end pieces, mount outside the 1200mm pieces' ends), 1x 800mm (gantry beam) | 5 pieces | generic 2040 stock, any supplier | [0010](decisions/0010-extrusion-profile-2040.md), [0035](decisions/0035-frame-corner-topology-rework.md), [0039](decisions/0039-y-axis-single-rail-dual-block.md) |
| Inside Hidden Corner Bracket, 90°, M5, 20-series | 1x 20-pack (need 16: 8 gantry + 8 frame, 2 per corner) | [Amazon](https://www.amazon.com/Pack-Inside-Hidden-Corner-Bracket/dp/B06XZ3Z82M) | [0028](decisions/0028-corner-bracket-hardware-selection.md) — **verify** leg length/set-screw position against physical part before cutting end caps |
| Caster wheel connector, 2020-series, M8 tapped | 1x 6-pack (need 4) | [Amazon](https://www.amazon.com/Connection-Connector-Aluminum-Extrusion-Thickness/dp/B0BW8SBLK8/) | [0034](decisions/0034-frame-feet-off-the-shelf.md) |
| M8 swivel leveling feet | 1x 6-pack (need 4) | [Amazon](https://www.amazon.com/Helonge-Levelers-Adjustable-Furniture-Workbench/dp/B08KXDFJ3M) | [0034](decisions/0034-frame-feet-off-the-shelf.md) |
| 20-series V-slot corner bracket (26mm leg, 25mm leg, M5, seats in the extrusion's own V-slot channel) | 30-pack w/ 60 screws (need 8: 4 per Y-gantry plate x 2 plates) | generic 20-series supplier | [0047](decisions/0047-captured-belt-custom-plates.md) — **still needs sourcing**, not yet ordered |

## Motion system

| Part | Qty | Source / link | ADR |
|---|---|---|---|
| 1-Pack Assembled 2040 V Gantry Plate Kit (aluminum plate, black-treated, 87x88x3mm, 6 POM wheels pre-mounted) | 3: one per connection point — 2 for X-axis gantry legs (one per leg), 1 for the Y-axis carriage | [Amazon](https://www.amazon.com/Assembled-Kit-Compatible-Aluminum-Extrusion/dp/B0B99WTBSY/), ~$18.99 each (confirmed via [WoodArtSupply](https://woodartsupply.com/products/1-pack-assembled-2040-v-gantry-plate-kit-with-6pcs-v-solid-pom-wheels-only-compatible-with-2040-4040-series-v-slot-aluminum-extrus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) carrying the identical item), ~$56.97 total | [0040](decisions/0040-x-axis-v-wheel-gantry.md), [0039](decisions/0039-y-axis-single-rail-dual-block.md) — replaces the custom PLA-CF plate + separate wheel-kit plan; **not yet redesigned**: needs redrawing for the aluminum plate's fixed bolt pattern (technical drawing now in hand: 87x88mm, R3 corners, 6x Ø7.2mm wheel-mount holes + 37x Ø5.1mm general mounting holes) |
| MGN12 linear rail + MGN12H carriage block | 1x 800mm rail (Y-axis, single rail on beam), 2x carriage blocks (both on the one Y rail) | generic MGN12 supplier — confirmed pricing at [LiMo Bearing](https://limobearing.com/mgn12c-mgn12h-mini-linear-sliding-rail): 800mm rail+block $21.07, spare slider $5.71 | [0008](decisions/0008-motion-system-mgn12-rails.md), [0039](decisions/0039-y-axis-single-rail-dual-block.md) — rail still provides the primary precise travel path; wheels above are reinforcement only, not a replacement |
| Socobeta NEMA17 motor mount bracket | 1x 5-pack (need 2: 1 Y shaft motor, 1 X carriage motor) | [Amazon](https://www.amazon.com/Socobeta-Stepper-Mounting-Bracket-Aluminum/dp/B0FPMDHTHD) | [0018](decisions/0018-motor-and-idler-mounts.md) — mounts the Ortur's 2 reused motors ([0041](decisions/0041-ortur-electronics-reuse.md), [0043](decisions/0043-adopt-ortur-axis-convention.md)) on the new frame; the standoff supporting the Y shaft's far end is a separate, not-yet-designed part |
| 6mm GT2 timing belt, closed loop | 2x ~1200mm loop (X) + 1x ~800mm loop (Y) | generic GT2 6mm stock | [0015](decisions/0015-x-axis-motor-system.md) |

**Motors and drivers**: reused from the existing Ortur LM2 S2 build, not
purchased — 1 NEMA17 with an extended shaft (coupler + standoff, driving
both sides of the gantry from one continuous shaft) on Y (800mm, gantry/
rail axis), 1 NEMA17 on X (1200mm, beam/carriage axis), driven by the
Ortur's own onboard drivers ([0041](decisions/0041-ortur-electronics-reuse.md),
[0043](decisions/0043-adopt-ortur-axis-convention.md)).

**Belt routing (both axes)**: captured belt drive — belt runs under the
gantry's wheels and over a pulley mounted between the top two wheels,
per [0048](decisions/0048-captured-belt-both-axes-no-idler.md) (extends
[0047](decisions/0047-captured-belt-custom-plates.md) from Y to X). No
idler pulley needed on either axis — the DiGiYes idler pulley and BEMONOC
drive pulley purchased for the original open-loop design are not part of
this design. Belt ends are anchored by the GT2 fixing clamp (see
3D-printed parts, below), not the 3DMAN clamps.

**Y-axis gantry plates**: custom-designed, laser-cut 5mm black acrylic —
[hardware/laser-cut/y-gantry-plate.svg](../hardware/laser-cut/y-gantry-plate.svg)
([0047](decisions/0047-captured-belt-custom-plates.md)). Reuses the
wheels/wheel-bolts from the purchased aluminum V-wheel plate kit (0040)
— that kit's own plate is not used, only its wheel hardware. Two
variants (motor side, bearing side, the latter holding a 625ZZ bearing
for the shaft's far end) plus 4 M5 holes per plate for the 20-series
corner L-brackets (already need sourcing — see below) that seat in the
2040 beam's V-slot for rigidity.

## Electronics & power

| Part | Qty | Source / link | ADR |
|---|---|---|---|
| LaserTree K40 laser module | 1 | LaserTree | [0041](decisions/0041-ortur-electronics-reuse.md), [0045](decisions/0045-revert-to-k40.md) — in hand and firing (2026-08-06); its bundled adapter board is **not used** (see below) |
| Mean Well LRS-350-24 PSU (24V, 14.6A) | 1 | generic Mean Well supplier | [0023](decisions/0023-power-supply-selection.md) — purchased but **not in the live power path**; the K40's bundled 24V/8A PSU runs the whole machine instead. Kept as a spare |

**K40 adapter board**: bundled with the K40, ultimately **not part of the
working wiring** — it powered the module (fan, temp indicator, marker
laser all worked) but never passed a PWM signal through, in either its
internal or external power mode. Bypassed by wiring the Ortur mainboard's
own laser-output pins (`LA_PWM`, `LA_PWR`, a `GND` pin) directly to the
K40's screw terminals via a spliced spare harness. See
[control system quick-reference](#control-system-quick-reference-if-the-controller-fails).

**Controller, drivers, wiring harness, and limit switches**: reused from
the existing Ortur LM2 S2 build ([0041](decisions/0041-ortur-electronics-reuse.md)),
not purchased.

Fuse coverage confirmed (2026-07-29): the fuse block kit's included set
(20A/15A/10A/7.5A/5A) didn't have the 3A/2A ratings this design needs —
closed by adding a full-range ATC/ATO assortment pack (1A-40A), which
covers every rating [0025](decisions/0025-24v-rail-fusing.md) calls for
exactly as speced. **Note**: [0025](decisions/0025-24v-rail-fusing.md)'s
per-branch fusing plan was written for the new stepper/controller wiring
this project was originally building — now that motors/controller/wiring
are reused from the Ortur ([0041](decisions/0041-ortur-electronics-reuse.md)),
that harness has its own existing fusing; the fuse block's role narrows to
the K40 rail only. Not yet re-checked against the actual reused harness.

~~Elastic cord/spring + cable anchors~~ — not needed. User already owns a
ceiling-suspended VR headset cable management system and will route the
spiral-wrapped bundle up to that instead of tensioning it along the frame
([0031](decisions/0031-cable-management.md)).

## Laser & air assist

| Part | Qty | Source / link | ADR |
|---|---|---|---|
| AquaMiracle 1000GPH air pump (35W) | 1 | generic aquarium/hydroponic supplier | [0005](decisions/0005-air-assist-pump-update.md) |

~~Silicone air tubing~~ — already had on hand.

## Fasteners & consumables (not separately tracked by ADR — generic hardware)

All items below already had, leftover from a previous build:

- ~~Assorted M3 and M5 socket-head/button-head screws, washers, T-nuts (2040/2020 standard)~~
- ~~M5 bolts for extrusion end-bore mounting (gantry end caps, corner joints)~~
- ~~Zip ties (cable management pass-throughs)~~

## 3D-printed parts (PLA-CF)

Everything that was ever planned as printed other than the two parts
below (idler mount, K40 carriage bracket, limit switch mount,
shaft-far-end bearing mount, Y gantry plate draft) has been eliminated
or moved to laser-cut acrylic — `hardware/3d-printed/` has been kept
clear of those superseded drafts (not just marked unused; git history
preserves them if ever needed).

| Part | Qty | Design file | ADR |
|---|---|---|---|
| GT2 fixing clamp | 8 | [hardware/3d-printed/gt2-fixing-clamp.stl](../hardware/3d-printed/gt2-fixing-clamp.stl) (source: user-downloaded model, "gt2-belt-clamp-techguy") | [0048](decisions/0048-captured-belt-both-axes-no-idler.md) — anchors the captured belt's ends on both axes. Print solid (100% infill), same creep-resistance rationale as this project's other tensioned printed parts |
| OLMP-V1.2C board mount | 1 | [hardware/3d-printed/olmp-board-mount.scad](../hardware/3d-printed/olmp-board-mount.scad) | [0049](decisions/0049-olmp-board-mount-3d-printed.md) — **interim only**, printed because no laser is running yet; the laser-cut acrylic version (below) is still the long-term part. Not yet test-fit against the physical board |

## Laser-cut parts (black acrylic)

| Part | Qty | Material | Design file | ADR |
|---|---|---|---|---|
~~Gantry end cap (2-layer laminate)~~ — superseded by the Y-axis gantry plate below, which does the same job ([0047](decisions/0047-captured-belt-custom-plates.md)); `gantry-end-cap.svg` kept for reference only, not built.
| Limit switch mount bracket | 2 (X and Y — the Ortur's own X switches, per [0041](decisions/0041-ortur-electronics-reuse.md), reused as-is) | 5mm black acrylic (default) | not yet designed — [hardware/3d-printed/limit-switch-mount.scad](../hardware/3d-printed/limit-switch-mount.scad) kept for reference only, needs redesign as a flat/joined acrylic part | [0033](decisions/0033-limit-switch-selection.md) — **not yet designed**: needs flat-pattern redesign (was a 3D-printed L-bracket) for the new 2040 frame; switch part and hole spacing are now a known/reused quantity (Ortur's own switches, [0041](decisions/0041-ortur-electronics-reuse.md)) rather than an estimate |
| Y-axis gantry plate (motor side + bearing side) | 2 (1 each) | 5mm black acrylic (working assumption, reference plate was 8mm) | [hardware/laser-cut/y-gantry-plate.svg](../hardware/laser-cut/y-gantry-plate.svg) — user-authored final design | [0047](decisions/0047-captured-belt-custom-plates.md) — **verify** 5mm thickness holds up under load. Attaches to the 2040 beam at 6 points: 2 tapped directly into the extrusion end + 4 through slotted L-bracket holes (slotted since no reliable reference exists for the bracket's exact hole spacing) |
| (all other future laser-cut parts) | — | 5mm black acrylic (default) | — | [0029](decisions/0029-laser-cut-material-selection.md) |

## Deferred / not part of this BOM

- Z-focus slider reprint for the interim 10W module — blocked on caliper measurements, not yet designed
- 3D-printed carrier for the spare 10W Ortur module — deferred, "not now"

## Known open verification items (do not treat these dimensions as final)

- Corner bracket leg length / set-screw position ([0028](decisions/0028-corner-bracket-hardware-selection.md))
- K40 sliding-plate mounting hole spacing ([0032](decisions/0032-y-axis-laser-carriage.md))
- Limit switch mounting-hole spacing ([0033](decisions/0033-limit-switch-selection.md))
- ~~Gantry end cap L-bracket slot dimensions~~ — moot, superseded by the Y-axis gantry plate ([0047](decisions/0047-captured-belt-custom-plates.md))
- K40 direct-mount to the wheel-holder plate: the plate's hole grid is fixed (not custom-drilled for the K40), may need new holes drilled once the K40's actual sliding-plate hole spacing is confirmed against physical hardware ([0032](decisions/0032-y-axis-laser-carriage.md), [0039](decisions/0039-y-axis-single-rail-dual-block.md))
- ~~Idler mount bracket bore/OD/width fit~~ — moot, idler pulleys eliminated entirely ([0048](decisions/0048-captured-belt-both-axes-no-idler.md))

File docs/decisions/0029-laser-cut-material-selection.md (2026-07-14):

# 0029. Laser-cut part material: 5mm black acrylic, uniform across all custom parts

Date: 2026-07-14
Status: Accepted

## Context

[0013](0013-gantry-end-plate-design.md) and [0016](0016-gantry-end-plate-rework.md)
both left the gantry end plate material as an open "plywood vs. acrylic,
thickness TBD" question, working from a placeholder assumption of 6mm per
laminated layer.

That question is now answerable in practical terms: cross-referencing
Ortur's own published cutting settings for the spare LU2-10A 10W module
(the one this machine will actually be cut with, at least until the K40
arrives, [0002](0002-laser-module-selection.md)) against independent
community consensus (manufacturer "cuts up to 30mm acrylic" claims are
unverified marketing hype nobody has reproduced) —

| Black acrylic thickness | Speed | Power | Passes |
|---|---|---|---|
| 3mm | 100 mm/min | 100% | 3 |
| 5mm | 100 mm/min | 100% | 3 |
| 8mm | 70 mm/min | 100% | 6 |

5mm is the practical sweet spot: same pass count and speed as 3mm, clean
established settings, comfortably within what the 10W module can do
without pushing into slow/many-pass territory. It's slightly thinner than
the 6mm working assumption baked into 0016's slot/laminate design, but
close enough that the existing geometry (in-plane slot widths, hole
positions) isn't invalidated — only the per-layer thickness figure changes.

## Decision

**All custom-designed laser-cut parts use 5mm black acrylic**, uniformly —
not plywood, and not mixed thicknesses per part. Parts that are
3D-printed (PLA-CF) remain 3D-printed; this decision only covers the
laser-cut category ([0003](0003-parts-sourcing-constraint.md)).

This updates [0016](0016-gantry-end-plate-rework.md)'s "6mm ply/acrylic"
working assumption to the now-confirmed 5mm black acrylic.

Category: material selection, applies retroactively to all existing and
future laser-cut part designs.

## Consequences

- Removes the open "plywood vs. acrylic, thickness" question from
  [0013](0013-gantry-end-plate-design.md)/[0016](0016-gantry-end-plate-rework.md) —
  every laser-cut part in this build now has a settled material/thickness
  to design against.
- The gantry end plates' laminated total thickness becomes 10mm (2x5mm)
  instead of the previously-assumed 12mm (2x6mm) — a minor change; doesn't
  affect any in-plane hole/slot position, only how far the corner
  bracket's leg (still unverified, [0028](0028-corner-bracket-hardware-selection.md))
  seats into the combined layer stack.
- Acrylic is more brittle than plywood — mounting points and screw holes in
  every laser-cut part should keep reasonable edge margins (consistent with
  the 15mm margins already used in [0013](0013-gantry-end-plate-design.md))
  to avoid cracking under clamping/vibration loads.
- Black acrylic is the deliberate choice for laser compatibility with the
  interim 10W module — cutting clear/light acrylic on that module would
  perform far worse (445nm diode light passes through transparent material
  with minimal absorption) even though it wouldn't matter once the K40
  (CO2-equivalent power, cuts either color similarly) is in use.
- The two existing gantry end plate SVGs
  ([hardware/laser-cut/gantry-end-plate-fixed.svg](../../hardware/laser-cut/gantry-end-plate-fixed.svg),
  [hardware/laser-cut/gantry-end-plate-floating.svg](../../hardware/laser-cut/gantry-end-plate-floating.svg))
  have had their material comment updated from the old 6mm assumption to
  the confirmed 5mm black acrylic.

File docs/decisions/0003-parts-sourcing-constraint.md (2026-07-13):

# 0003. Parts sourcing constraint: off-the-shelf, PLA-CF printed, or laser cut

Date: 2026-07-13
Status: Accepted

## Context

This is a DIY build with a specific fabrication toolset available: a 3D
printer capable of PLA-CF, and the laser cutter itself (see [0002](0002-laser-module-selection.md)
for why we're upgrading it). We want every part in the design to be something
that can actually be acquired or made without needing tools/processes we
don't have (e.g. no machining, no injection molding, no parts requiring
sourcing from obscure/hard-to-find suppliers).

## Decision

Every part in this machine must fall into exactly one of these categories:

1. **Off-the-shelf** — a component that can be ordered easily from a normal
   supplier (McMaster-Carr, Amazon, AliExpress, OpenBuilds, etc.). Linear
   rails, bearings, belts, steppers, drivers, fasteners, the laser module
   itself, PSU, etc.
2. **3D printed in PLA-CF** — brackets, mounts, carriages, panels, or other
   structural/functional parts we design and print ourselves. Since PLA-CF is
   more rigid and less prone to warping/creep than plain PLA but is still
   somewhat brittle and has lower heat tolerance than nylon/PETG-CF, parts
   should avoid thin-walled high-stress features and stay clear of the laser
   module's heat zone.
3. **Cut on our existing laser cutter** — flat panels/plates (e.g. frame
   panels, gussets, gantry plates) cut from sheet stock (plywood, acrylic,
   MDF) up to whatever thickness our *current* machine can cut, since the new
   machine isn't built yet.

No part may require CNC machining, injection molding, casting, welding, or
sourcing from a supplier that isn't a standard easy-to-order channel.

## Consequences

- Every design decision from here forward should note which of these three
  categories each part falls into.
- Some tradeoffs are forced: e.g. we can't spec precision-machined aluminum
  brackets even if they'd be structurally nicer — we need an off-the-shelf
  equivalent, a PLA-CF printed part, or a laser-cut panel instead.
- The laser-cut category is thickness-limited by our *current* 10W Ortur
  module until the new machine exists — this may constrain frame panel
  thickness choices for laser-cut parts (e.g. limits to thin plywood/MDF/
  acrylic, not the 1/2" birch the new machine is meant to cut).
- PLA-CF's heat sensitivity means any bracket close to the laser module or
  in the exhaust path needs extra clearance or a heat shield, rather than
  relying on the material's own heat resistance.

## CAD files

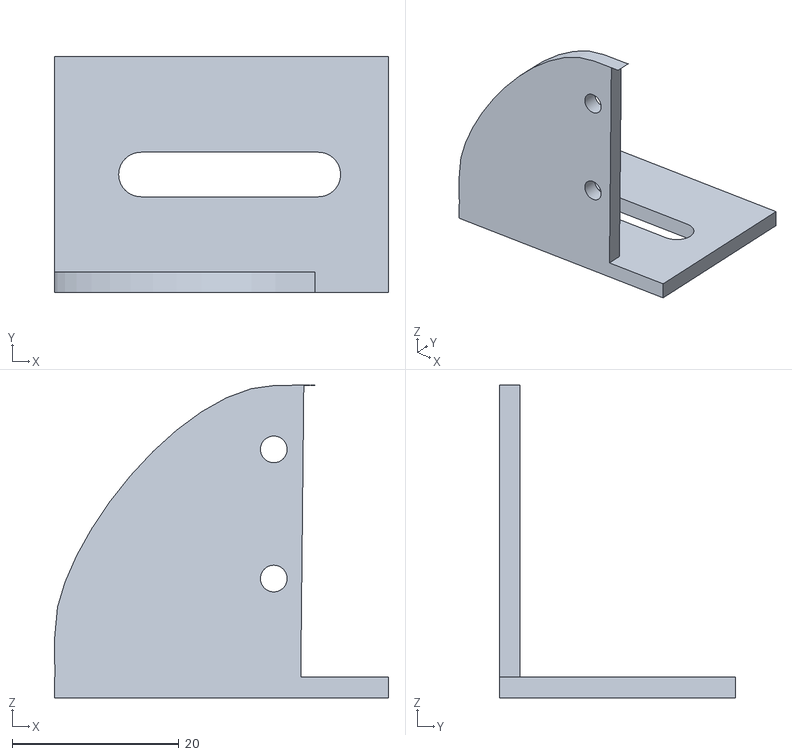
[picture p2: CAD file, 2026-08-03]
hardware/3d-printed/olmp-board-mount.stl
40.1 x 28.4 x 37.5

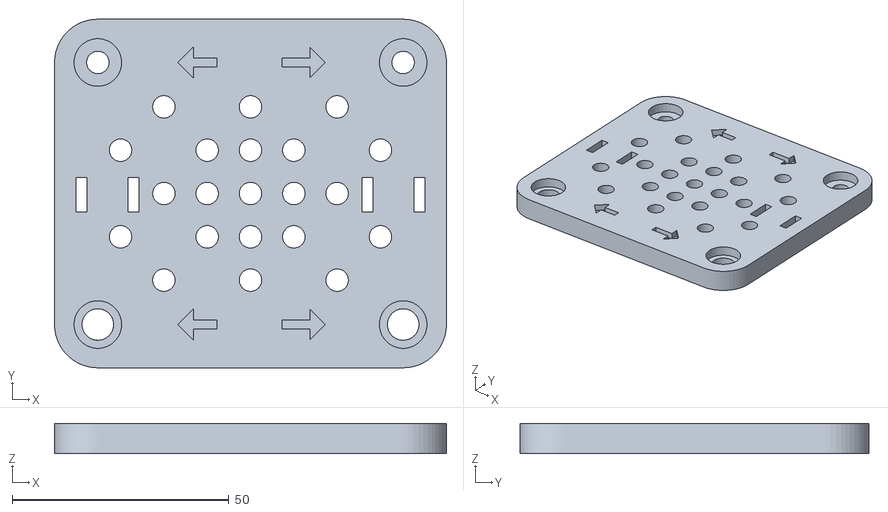
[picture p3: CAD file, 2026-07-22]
hardware/laser-cut/20x40.stl
90.5 x 80.5 x 7.00

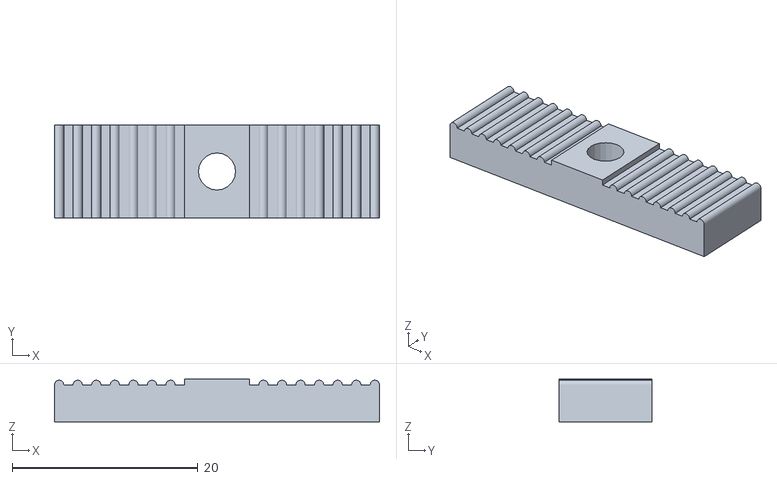
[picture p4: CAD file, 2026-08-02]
hardware/3d-printed/gt2-fixing-clamp.stl
35.0 x 10.0 x 4.62

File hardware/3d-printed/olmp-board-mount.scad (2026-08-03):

// OLMP-V1.2C board mount, 3D-printed (interim, until laser cutter is
// rebuilt - see docs/decisions/0049-olmp-board-mount-3d-printed.md).
//
// Direct translation of Reference/olmp-board-mount-build reference.svg
// (FRONT/TOP/SIDE layers). Genuine L-bracket: thin vertical wall +
// thin horizontal foot (both 2.5mm, per the SIDE layer), not a solid
// wedge - the SIDE layer is two ~2.4mm-thick rectangles meeting at a
// corner, i.e. an actual L cross-section.
//
// Axes: X = width (u, FRONT/TOP left-right), Y = depth (d, TOP/SIDE
// front-back), Z = height (w, FRONT/SIDE up-down).
//
// Units: mm.

$fn = 64;

// --- exact FRONT profile outline (wall's own front-facing silhouette),
// traced from the SVG path/bezier curves, as (u, -w) pairs ready for
// linear_extrude + rotate([-90,0,0]) (see wall() below). Updated per
// the user's edit: front narrowed to 29.55mm (was 40.08mm), left edge
// held in place so it still aligns with the foot's left edge - the
// wall no longer spans the foot's full width, intentionally. ---
front_profile = [
    [26.506,-35.0], [29.7,-35.019], [31.095,-35.024], [31.234,-35.02],
    [30.661,-35.012], [29.919,-35.004], [29.551,-0.0], [0.08,-0.0],
    [0.074,-0.119], [0.061,-0.459], [0.044,-0.993], [0.025,-1.697],
    [0.01,-2.543], [0.0,-3.506], [0.0,-4.56], [0.36,-8.401],
    [1.259,-11.394], [2.646,-14.562], [4.459,-17.807], [6.631,-21.034],
    [9.099,-24.145], [11.798,-27.045], [14.664,-29.638], [17.632,-31.826],
    [20.638,-33.513], [23.617,-34.603], [26.506,-35.0],
];
foot_width = 40.08; // unchanged - the TOP layer wasn't touched

// --- M3 board holes, exact FRONT-layer circle positions (u, w) ---
hole_u = 26.314;             // moved left with the narrowed front
hole_w = [11.816, 27.316];   // unchanged - 15.5mm apart, as drawn
hole_dia = 3.2;              // as drawn (2x1.6mm radius)

// --- SIDE-layer L cross-section thicknesses ---
wall_t = 2.5;   // vertical wall thickness (D), rect8 (2.424mm drawn)
foot_t = 2.5;   // horizontal foot thickness (W), rect9 (2.432mm drawn)
foot_d = 28.373; // foot depth/length (D), rect9's drawn length

// --- TOP-layer M5 slide slot, long axis along U (parallel to the
// front wall) ---
slot_u        = 21.016;  // slot center, distance from the shared left edge
slot_d        = foot_d / 2;  // centered front-to-back in the foot (was
                              // 10.857, off-center per the TOP layer) so
                              // there's equal clearance for the bolt head
                              // on both sides
slot_len      = 26.625;  // full stadium length (u axis)
slot_width    = 5.34;    // as drawn (~5.5mm stated)
slot_straight = slot_len - slot_width;

module wall() {
    difference() {
        rotate([-90, 0, 0])
            linear_extrude(height = wall_t)
                polygon(points = front_profile);

        for (w = hole_w)
            translate([hole_u, -1, w])
                rotate([-90, 0, 0])
                    cylinder(h = wall_t + 2, d = hole_dia);
    }
}

module foot() {
    difference() {
        translate([0, 0, -foot_t])
            cube([foot_width, foot_d, foot_t + 0.01]); // +0.01 overlap into the wall for a clean union

        translate([slot_u, slot_d, -foot_t - 1])
            hull() {
                translate([-slot_straight/2, 0, 0]) cylinder(h = foot_t + 2, d = slot_width);
                translate([ slot_straight/2, 0, 0]) cylinder(h = foot_t + 2, d = slot_width);
            }
    }
}

module olmp_board_mount() {
    union() {
        wall();
        foot();
    }
}

olmp_board_mount();

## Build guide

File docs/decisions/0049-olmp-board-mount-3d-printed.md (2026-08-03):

# 0049. OLMP-V1.2C board mount: 3D-printed, interim

Date: 2026-08-03
Status: Accepted (interim; the laser-cut acrylic version from the same
commit as this ADR remains the intended long-term part once the new
machine is cutting)

## Context

The old Ortur is being torn down for parts and the new machine isn't
running yet, so nothing can be laser-cut right now. The OLMP-V1.2C
board (12V/GND/PWM/KEY, integrated pushbutton, carries the 1200mm-axis
limit switch) needs a mount now, not once the laser is back online.

User provided a scaled reference sketch
([Reference/olmp-board-mount-build reference.svg](../../Reference/olmp-board-mount-build%20reference.svg),
FRONT/TOP/SIDE layers, holes marked with grey infill) and a reference
STL of a standard 30mm corner L-bracket
([Reference/scb_30.stl](../../Reference/scb_30.stl)) to show the
general shape being targeted — not a literal trace, just the L-bracket
silhouette. Board itself: 20x20mm, 2x M3 bolts (2.8mm measured)
15.5mm center-to-center (confirmed again from the FRONT-layer holes).
The board must be slidable along the V-slot extrusion to position the
limit switch correctly once the gantry is assembled.

## Decision

3D-printed part, [hardware/3d-printed/olmp-board-mount.scad](../../hardware/3d-printed/olmp-board-mount.scad),
a genuine L-bracket — direct translation of the reference sketch's
three views:

- **Vertical wall**: the FRONT layer's exact outline (flat bottom
  edge, short left edge, one long curved sweep up to the narrow
  top-right strip that carries the board holes), as a thin **2.5mm**
  plate (matches the SIDE layer's rect8, drawn 2.424mm) — not a solid
  extrusion. Printed solid PLA-CF, no added ribs/gusset needed.
  **Narrowed to 29.55mm** (was 40.08mm, matching the foot) per a
  follow-up edit to the FRONT layer — left edge held in place so it
  still aligns with the foot's left edge; the wall intentionally no
  longer spans the foot's full width. Holes moved left with it (still
  15.5mm apart, same height).
- **Horizontal foot**: a plain rectangle, **40.08mm wide** (unchanged,
  wider than the wall — intentional, per the same edit), thin
  **2.5mm** plate (SIDE layer's rect9, drawn 2.432mm) at the wall's
  base, extending 28.373mm in depth (rect9's drawn length) — a real L
  cross-section, not a solid wedge. Left-aligned with the wall.
- **M3 board holes**: exact FRONT-layer circle positions, 15.5mm
  apart, 3.2mm diameter as drawn, through the wall only.
- **M5 slide slot**: TOP-layer stadium size (5.34mm wide, 26.6mm
  long), through the foot only, long axis parallel to the front wall
  (along the width axis). **Depth position centered** in the foot
  (14.19mm from both the wall and the back edge) rather than the
  TOP layer's off-center position (10.86mm from the near edge) — so
  there's equal clearance for the bolt head on either side.
- **Real assumption, not yet verified**: no clearance cut for the
  board's connectors (reverse side, per the user) — the board's own
  bolts are assumed to give enough standoff.

## Consequences

- This becomes the build's 2nd 3D-printed part (with
  `gt2-fixing-clamp.stl`), out of necessity — not a reversal of the
  laser-cut-by-default preference ([0048](0048-captured-belt-both-axes-no-idler.md)).
- The laser-cut acrylic version
  ([hardware/laser-cut/olmp-board-mount.svg](../../hardware/laser-cut/olmp-board-mount.svg))
  is not superseded — once the new machine is running, it's still the
  intended long-term part. This ADR only covers the interim print.
- Real open follow-up: physically test-fit the print against the
  board before trusting the connector clearance assumption above.

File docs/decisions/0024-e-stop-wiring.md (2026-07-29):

# 0024. E-stop wiring: AC-side panic-paddle switch (was: DC dual-channel relay design)

Date: 2026-07-14
Status: **Superseded 2026-07-29** — the DC-side mushroom switch + relay
design below is cut entirely, replaced with an AC-side panic-paddle
safety switch ahead of the whole machine. Kept below for history/rationale.

## Update (2026-07-29): AC-side panic-paddle switch, no DC relay

User's call: skip the DC-side E-stop switch/relay pair entirely. Power
for the whole machine — the Mean Well 24V rail (steppers/controller) and
the K40's own 24V/8A adapter — both run off one already-owned power
strip. Added to that: a **110-120V AC panic-paddle safety switch**
(marketed for table saws/milling machines — large red stop-sign paddle,
on/off, mains-rated) wired ahead of the strip, so hitting the paddle cuts
mains power to the entire setup at once.

This actually restores most of what the original design provided,
just via a different mechanism:
- **Panic-reflex speed**: a large paddle switch is exactly the
  "hit-it-without-looking" ergonomics a mushroom button gives — this
  wasn't a downgrade after all, just moved from the DC side to the AC
  side.
- **Hardware-guaranteed cutoff**: an AC-side mains switch ahead of *both*
  the steppers/controller PSU and the K40's adapter is arguably a more
  complete guarantee than the original design, which only hard-cut the
  K40's rail — this cuts everything, including the controller itself,
  independent of firmware state.

**What's still genuinely different from the original dual-channel
design**: no separate *software* Halt signal to the controller — the
original design gave grblHAL a fast, controlled stop (steppers decelerate
via firmware) as one channel, with the hardware relay as a second,
independent guarantee. This paddle switch is now the only channel: it's
an abrupt full power cut, not a graceful stop, and there's no longer a
distinct low-level Halt input wired at all ([0026](0026-t41u5xbb-pin-mapping.md)).
For a hobby laser (vs. a machine where uncontrolled motor stop is itself
a hazard), this is a reasonable tradeoff — noted once, not a blocker.

**What this removes from the BOM**: the 22mm mushroom E-stop switch and
the 24VDC SPDT relay are no longer needed (switch already in hand —
consider it a surplus/return candidate). The K40 rail's fuse between the
adapter and the module ([0025](0025-24v-rail-fusing.md)) still applies
for overcurrent protection — it's just no longer gated by a relay,
straight adapter-to-module with a fuse in line.

**What's added to the BOM**: the AC panic-paddle switch itself, wired
ahead of the already-owned power strip.

---

**Original decision below, superseded but kept for context:**

## Context

The T41U5XBB's manual (v2.07) documents a dedicated **Halt/Stop** control
input — one of four opto-isolated control inputs (Feed Hold, Cycle Start,
Halt/Stop, Safety Door), 5V logic, wired via screw terminal. This is
grblHAL's E-stop equivalent: triggering it immediately stops motion and
puts the system in an Alarm state. The manual explicitly recommends *"you
do not disable the Halt function and that you install a dedicated Halt
button in a prominent location on your CNC machine."*

However, the Halt input alone is a **software-mediated** stop — grblHAL
sees the input change and reacts by halting steppers and de-asserting the
spindle/laser PWM output. That's near-instant, but it depends on the
firmware/controller being responsive. A real E-stop's value is in *not*
depending on that: it should still work if the board has locked up or a
firmware bug leaves the laser firing.

This matters concretely here because the K40 laser module has **its own
dedicated 24V/8A power adapter**, entirely independent from the Mean Well
LRS-350-24 rail that powers the steppers and controller
([0023](0023-power-supply-selection.md)). A single E-stop button needs to
reach both power domains: signal the controller to halt motion, and
physically remove power from the K40 so the diode cannot fire regardless
of what the firmware is doing.

Confirmed while researching this: the K40's 3-pin TTL/PWM control cable
(2EDG-3.81 connector: red VCC, black GND, yellow PWM/TTL) expects a
standard 5V TTL logic signal — LaserTree's own documentation lists
compatibility with Ortur/Neje/Sculpfun/etc. control boards, all of which
output 5V TTL. The T41U5XBB's spindle-group PWM/Direction/Enable output is
explicitly "a 5V group" per its manual. This resolves the open question
from [0022](0022-controller-board-selection.md) about the K40's exact PWM
voltage spec — it's a standard match, no level-shifting needed.

## Decision

**Dual-channel E-stop**, using a double-pole (2NC), latching 22mm mushroom
button (push-to-stop, twist-to-release — e.g. uxcell/mxuteuk-style
generic CNC E-stop switch, ~$10), mounted in a prominent, easy-to-reach
spot on the frame.

- **Pole 1** wired NC in series with the T41U5XBB's **Halt/Stop** screw
  terminal — standard grblHAL control-input wiring (switch between the
  Halt signal pin and its ground reference). This is the fast,
  firmware-level stop: motion halts, grblHAL enters Alarm state, spindle/
  laser PWM output is de-asserted in software.
- **Pole 2** wired NC in series with the coil of a 24VDC automotive-style
  SPDT relay (rated ≥15A, well above the K40's 8A draw), which is inserted
  in-line on the K40's 24V/8A adapter output — between the adapter and the
  module's main power input (not the TTL/PWM control cable). Pressing
  E-stop de-energizes the relay coil, opening the contacts and removing
  **all power** from the K40 module. This is the hardware-guaranteed half:
  the laser diode cannot fire without power, independent of firmware
  state.

Using NC (normally-closed) contacts on both poles, per grblHAL's own
recommendation — a broken wire or bad connection then reads as a fault
(system halts) rather than silently failing open.

Category: off-the-shelf (E-stop switch, relay).

## Consequences

- Two independent stop paths for the two things that actually need
  stopping: motion (software Halt, near-instant but firmware-dependent)
  and laser fire (hardware relay cutoff, guaranteed regardless of
  firmware/controller state).
- Steppers losing power abruptly on E-stop is an accepted tradeoff — unlike
  an active laser diode, de-energized steppers mid-motion aren't a
  personal-safety hazard for this machine.
- New hardware needed: 1x 2NC mushroom E-stop switch, 1x 24VDC SPDT relay
  (with flyback protection/socket), wire gauge matched to the K40's 8A draw
  on the switched leg.
- The relay's switched leg should get its own fuse as part of the
  still-open per-branch fusing design ([0023](0023-power-supply-selection.md))
  — sized for the K40's 8A draw plus headroom (~10A).
- grblHAL's `$14` (control pin invert mask) should be left at default for
  NC wiring (inversion is only needed for NO switches) — worth confirming
  at commissioning once the board is wired and flashed.
- Does **not** yet cover a Safety Door input (separate open item, not
  requested here) — the enclosure/downdraft-table setup
  ([0006](0006-bed-and-enclosure-scope.md)) doesn't currently have a door
  sensor, so `$14`'s Safety Door bit will need inverting (or a jumper
  installed) so grblHAL doesn't sit in a permanent door-open alarm state.

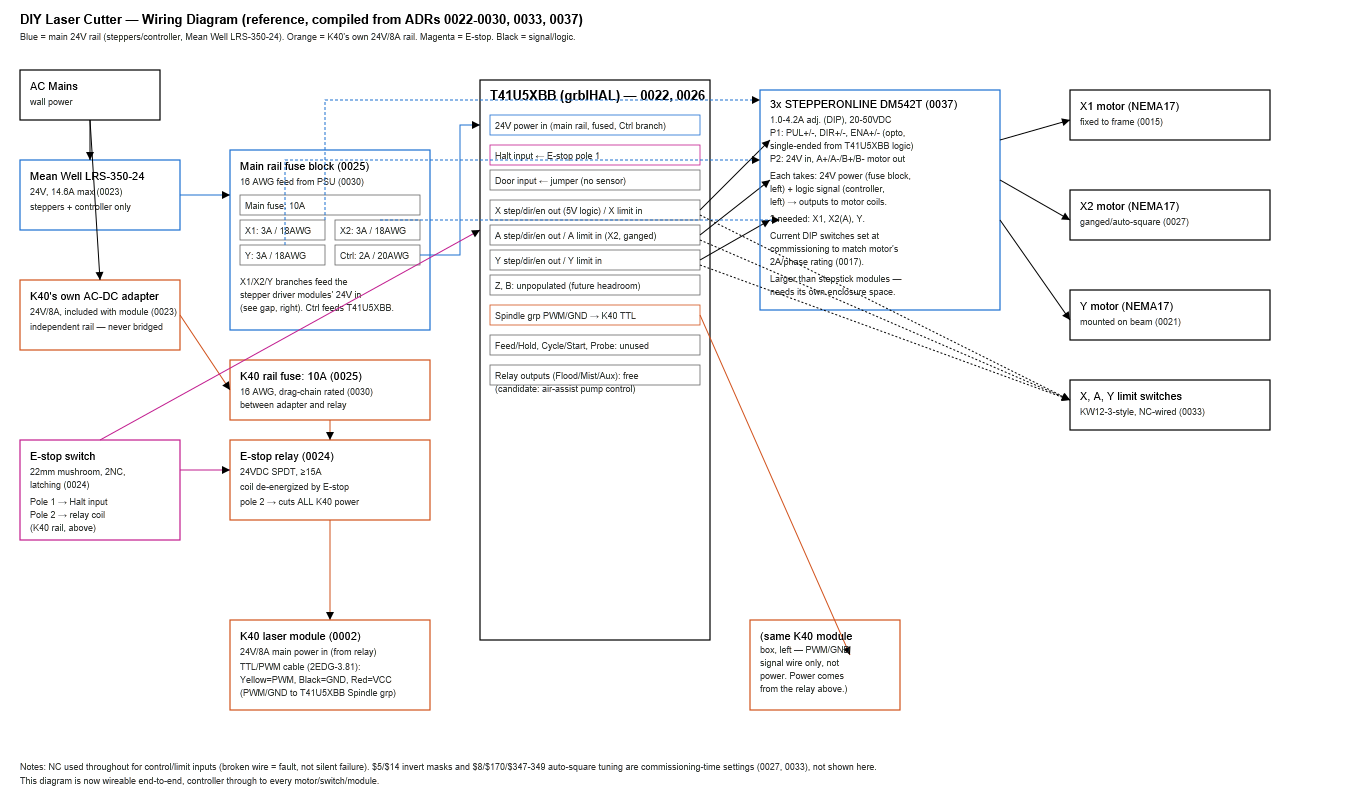
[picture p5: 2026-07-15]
docs/reference/wiring-diagram.png

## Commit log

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2026-07-13 Note silicone tubing resolves fitting-size concern
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2026-07-13 Record frame footprint constraint: 800mm axis fixed, 1.2m axis flexible
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2026-07-13 Estimate current machine frame footprint on fixed axis; add 4ft ceiling on flexible axis
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2026-07-13 Correct axis naming to match Ortur/GRBL convention: Y=800mm, X=long axis
2026-07-13 Correct mechanical axis roles: Y=guide rails/whole-gantry (800mm), X=beam span/carriage (long axis); delete gantry end plate SVG for rework
2026-07-13 Add ADR: Y-axis motor system (fixed motors/idlers, 6mm GT2, off-the-shelf mounts)
2026-07-13 Rework gantry end plates: L-bracket joint, laminated dual-layer, asymmetric fixed/floating pair
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2026-07-13 Reverse gantry topology: guide rails on long 1200mm axis (X) for lower moving mass, beam on fixed 800mm axis (Y); document end plate mounting orientation
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2026-07-13 Add ADR: motor mount and idler mount hardware (idler pulley pending user-sourced link)
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2026-07-13 Select belt clamp hardware and add mounting holes to gantry end plates
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2026-07-13 Correct: K40 includes its own 24V/8A power adapter; resize main PSU to LRS-350-24
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2026-07-14 Add 0024: dual-channel E-stop wiring (Halt input + K40 relay cutoff)
    Resolves how a single E-stop button reaches both independent power
    domains (Mean Well rail vs. the K40's own 24V/8A adapter), and confirms
    the K40's TTL/PWM signal is standard 5V logic, closing the PWM-spec
    question left open in 0022.
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2026-07-14 Add 0026-0027: T41U5XBB pin mapping and grblHAL auto-square config
    0026 confirms the physical wiring assignment (X1/X2-via-A/Y, Halt/Door,
    Spindle group to K40 TTL) so assembly doesn't require guessing terminals.
    0027 confirms auto-squaring requires custom-compiled firmware
    (X_GANGED/X_AUTO_SQUARE) rather than a runtime setting, and separates out
    the $ tuning values that can only be set once the gantry is physically
    wired and homed.
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2026-07-14 Add 0030: wire gauge per 24V fuse branch
    Sizes wire for every branch from 0025's fuse ratings, using standard
    chassis-wiring ampacity as a baseline and stepping up one gauge for
    screw-terminal robustness and (for the K40 branch specifically)
    drag-chain flex durability. Closes out the last open item from the
    electrical/firmware punch list (0024-0030).
2026-07-14 Add 0031-0032: cable management + Y-axis laser carriage (with model)
    0031 records the spiral-wrap + tensioned-support cable management
    approach for both the X-level and Y-level moving cable runs, in place
    of a drag chain.
    0032 closes the biggest gap found in the full-repo review: the part
    that actually holds the K40 on the Y-axis carriage was never designed
    (flagged as open since 0021). Decides the beam's own rail-mounting
    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
    [y-carriage-k40-bracket.scad, y-carriage-k40-bracket.stl]
2026-07-14 Add 0033: limit switch selection + mounting bracket (with model)
    Picks a KW12-3-style SPDT microswitch (NC-wired, consistent with the
    E-stop's NC philosophy from 0024) and designs a PLA-CF T-slot-mounted
    bracket with slotted adjustment, since exact switch dimensions aren't
    reliably published across sellers -- same treatment as the corner
    bracket and K40 mount research. Includes a real parametric OpenSCAD
    model + exported STL.
    [limit-switch-mount.scad, limit-switch-mount.stl]
2026-07-15 Add 0034: switch frame feet to off-the-shelf leveling feet
    Replaces 0012's custom PLA-CF foot plan with off-the-shelf M5
    adjustable leveling feet for 20-series extrusion, dropping the
    table-screw-down requirement -- the frame itself is stationary, so
    weight + swivel-pad friction is judged sufficient. No custom part or
    modeling needed; corner-joint half of 0012 is unaffected.
2026-07-15 Update 0034: confirmed feet product pairing (connector + M8 foot)
    Replaces the generic "any M5/M8 foot works" language with a verified
    combo: heneng's 2020-series extrusion connector (M8 tapped hole) paired
    with Helonge's M8 swivel leveling feet -- thread sizes confirmed to
    actually mate, both sold as matching 6-packs.
2026-07-15 Add 0035-0036: frame corner topology rework + gantry end cap redesign
    0035: 1200mm frame pieces stay full length; 800mm end pieces mount
    outside their ends instead of flush mid-corner; X-rails move to the
    1200mm pieces' outside face. Outer footprint grows 800x1200 -> 800x1240,
    deliberately exceeding 0007's old 1219mm ceiling -- absorbed by
    downdraft table tolerance + adjustable leveling feet (0034), not an
    oversight.
    0036: supersedes 0016 entirely. Beam-length tolerance moves to the
    frame corner joint above, so both gantry ends can be identical, solid
    front+back plate pairs instead of the old asymmetric fixed/floating
    design. New design file replaces the superseded fixed/floating SVGs.
    Als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
2026-07-15 Fix gantry-end-cap.svg: stack L-bracket slots vertically, fix hole margin
    The beam installs wide-face-vertical (ADR 0032), so the wide face's two
    T-slots are stacked one above the other in real life, not side by side
    as the previous version drew them. Also fixes the carriage mount holes,
    which had a row sitting exactly on the plate's bottom edge instead of
    fully inside the body -- increased plate height to give proper margin.
2026-07-15 Fix gantry-end-cap.svg scale error: contain slots within real 20x40 footprint
    The L-bracket slots were previously at the wrong scale/orientation and
    one extended to y=56-78, well past the extrusion's actual 40mm-tall
    cross-section (8-48). Adds a dashed reference rect showing the true
    20x40mm footprint and repositions both slots (now 22w x 10h, rotated
    to match the wide-face-vertical beam orientation) fully within it.
    Dimensions remain a working estimate pending real bracket measurement.
2026-07-15 Add 0037: stepper driver selection + full wiring diagram
    Building the wiring diagram surfaced a real gap: no ADR had ever
    selected actual stepper driver modules -- only the motors (0017) were
    chosen, and the T41U5XBB only outputs 5V logic step/dir/enable signals,
    not enough to drive motor coils directly. Resolves with 3x STEPPERONLINE
    DM542T (same brand as the motors, real manufacturer datasheet with
    confirmed opto-isolated pinout).
    Adds docs/reference/wiring-diagram.svg (+ PNG export) as the single
    reference tying together the controller, both 24V rails, fusing,
    E-stop, drivers, motors, limit switches, and the K40 -- traceable
    end-to-end from AC mains to every destination.
2026-07-16 Add consolidated BOM across all 37 ADRs
    Single shopping list pulling every part, quantity, and purchase link
    from docs/decisions/ into one document, organized by subsystem. Flags
    the known open verification items (corner bracket, K40 mount, limit
    switch, gantry end cap dimensions) so they aren't mistaken for final.
    Also adds the DM542T purchase link that 0037 referenced but never
    actually linked.
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2026-07-22 Add ADR 0038: Y-axis dual-rail carriage, beam upgraded to 2060
    K40's cantilevered weight on a single MGN12 rail was a real
    stiffness/deflection concern for laser focus/pointing, not just a load
    question. Adds a second rail on the beam's two outer T-slots (40mm
    apart) rather than accepting the cantilever.
    - Beam extrusion: 2040 -> 2060 (beam only, rest of frame unchanged)
    - Y-carriage bracket widened for two MGN12H mount patterns, 40mm apart
    - Gantry end cap reference geometry and L-bracket slots updated to the
    2060 footprint, using the beam's outer T-slots to match
    - BOM updated for the new beam stock and second rail/block
    - 0021 cross-referenced now that Y rides two passive rails (still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
    [y-carriage-k40-bracket.scad, y-carriage-k40-bracket.stl]
2026-07-22 Add ADR 0039: Y-axis single rail with dual carriage block, supersedes 0038
    A real price check (LiMo Bearing) found 0038's dual-rail/2060-beam
    approach costs more than it needs to, and that an HGR15 brand swap is
    pricier still since it's only sold as a fixed 2-rail bundle. Mounting two
    MGN12H blocks on one rail, spaced along the rail's own travel direction,
    resists the same K40 cantilever moment as a second rail would, for about
    $15 less per Y-axis set - and lets the beam revert to plain 2040.
    - Beam reverts to 2040 (single BOM line again, no separate 2060 line)
    - Y-axis: 1 rail, 2 blocks (spine bracket spans both block positions,
    standoff/K40 arm hangs from the center) instead of 2 rails,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
    [y-carriage-k40-bracket.scad, y-carriage-k40-bracket.stl]
2026-07-22 Add ADR 0040: X-axis V-wheel gantry plates, replacing MGN12 rail
    The X-axis's two 1200mm MGN12 rails were the single most expensive
    motion-system line item ($63.26). Swapping to 2040-compatible V-wheel
    gantry plate kits (Creality3D Parts, $13.99 each) covers both sides for
    $27.98 - a $35.28 saving, accepted along with the wear/precision tradeoff
    V-wheels carry versus MGN12 on this, the heaviest-loaded axis.
    Shopping list only for now: the gantry end cap still cuts its carriage
    mount for the MGN12H block's bolt pattern, not this plate's. That
    mechanical redesign is intentionally deferred to a follow-on task.
2026-07-22 Add custom universal plate for gantry legs, price V-wheels separately
    User provided a custom mounting plate design (hardware/laser-cut/20x40.stl,
    90.5x80.5x7mm, corner holes + diamond-grid pattern) as the intended
    connection point for both the X-axis gantry legs and eventually the
    Y-axis carriage, replacing the pre-made gantry-plate-kit approach in
    0040. Wheels now sourced standalone: a 10-pack of assembled Delrin Mini
    V-Wheels (wheel + bearing + eccentric spacer) at $16.00 covers the 8
    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
    [20x40.stl]
2026-07-22 Correct wheel count to 12: Y-axis carriage also gets reinforcement wheels
    Missed that the Y-axis carriage keeps its rail as the primary travel
    path but also picks up 4 wheels as anti-wiggle reinforcement (the hybrid
    rail+wheel design), on its own custom plate - same part as the X-axis
    gantry legs. Total is 12 wheels (8 X-axis + 4 Y-axis) and 3 plates (2 X +
    1 Y), not 8/2. Updated BOM and both ADRs (0039, 0040) to match.
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2026-07-22 Correct wheel-holder plate count: 3 total, one per connection point
    The "front+back plate pair" design from the last session was a
    misreading. The user clarified: there are 3 connection points (2 X-axis
    gantry legs + 1 Y-axis carriage), each gets exactly one wheel-holder
    plate (4 wheels apiece) - not a doubled pair. Wheel count (12) was
    already correct and is unchanged; only the plate count drops from 6 back
    to 3. The earlier "back plate for stability" note turned out to describe
    the Y-axis carriage's own body construction (possibly two plates),
    separate from the wheel-holder plate - tracked as its own open item.
    Also logged a confirmed off-the-shelf aluminum alternative (~$18.99/
    plate, 6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
2026-07-22 Switch to pre-made aluminum V-wheel plate kit, 3x, final sourcing
    Decided against the custom PLA-CF plate + separately-sourced wheels in
    favor of the off-the-shelf aluminum kit already identified as a fallback
    - "1-Pack Assembled 2040 V Gantry Plate Kit" (Amazon B0B99WTBSY,
    ~$18.99 each): aluminum plate, 87x88x3mm, 6 POM wheels pre-mounted.
    One plate per connection point (2 X-axis gantry legs + 1 Y-axis
    carriage) = 3 plates, 18 wheels, ~$56.97 total.
    Removes the need for the separate Delrin Mini V-Wheel purchase (wheels
    now bundled) and the print-settings note (bought assembled, not
    printed). hardware/laser-cut/20x40.stl kept in the repo for reference
    but is no longer the sourced part.
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2026-07-29 Finalize Y-axis carriage: K40 bolts directly to the wheel-plate
    Simplest option chosen - no separate bracket (acrylic or PLA-CF) at
    all. The wheel-holder plate is now the entire carriage body: connects
    to both MGN12H rail blocks, carries the anti-tip wheels, and mounts the
    K40 directly on its own hole grid. Supersedes
    y-carriage-k40-bracket.scad for the Y-axis (kept in repo for reference,
    not built).
    Flagged the real remaining risk: the plate's hole grid is fixed, not
    custom-drilled for the K40, so new holes may need to be drilled once
    the K40's actual mounting pattern is confirmed.
2026-07-29 Switch limit switch mounts from PLA-CF print to laser-cut acrylic
    Matches the black acrylic stock already being ordered. This is a real
    geometry change, not just a material swap - the current design is a
    single-piece 3D-printed L-bracket, which doesn't translate directly to
    a flat laser-cut part. Flagged as not-yet-designed, deferred alongside
    the switch's own still-unverified hole spacing until the actual switch
    is in hand. Old .scad kept in repo for reference, no longer built.
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2026-07-29 Switch idler mount to 3D-printed PLA-CF (purchased kit unavailable)
    The OpenBuilds-style bolt+spacer+locknut kit for the idler mount is no
    longer available. Switching to a printed PLA-CF part instead: JeSc
    HyperCube XY Idler T16 v2.0 (Printables), to be downloaded into the new
    Printables/ folder. User already has PLA-CF filament.
    Flagged honestly: this reopens the exact PLA-CF creep/flex concern
    0018's own Context section raised against printing constantly-tensioned
    anchor points in the first place - not a reason to block the switch,
    just worth knowing. Also flagged as unverified: this print's "T16"
    naming references a 16-tooth pulley from its original application,
    which may not match our a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
2026-07-29 Correct idler mount verification note: dimension check, not tooth-count mismatch
2026-07-29 Note idler mount will print solid, resolving the creep/flex concern
    Solid (100%) infill directly addresses the PLA-CF creep/flex risk this
    ADR originally flagged against printing constantly-tensioned anchor
    points - deliberately different from this build's other printed parts
    (15% infill). Also noted the user will modify the model file directly
    if the DiGiYes idler doesn't fit as downloaded.
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2026-07-29 Remove E-stop switch/relay, replace with a single switched power strip
    User's call: skip dedicated E-stop hardware entirely. The whole machine
    (steppers/controller PSU and the K40's own adapter) plugs into one
    switched power strip, and that switch is now the emergency shutoff.
    Flagged once for the record in 0024: this trades away the panic-reflex
    mushroom button and the dual independent stop paths (fast software Halt
    vs. guaranteed hardware laser power cut) for a single switch that kills
    everything at once. Not blocking the change, just on the record.
    Updated 0025 (K40 rail now runs adapter-to-module with just a fuse, no
    relay) and 0026 (Halt input now unpopulated - the board's manual
    reco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
2026-07-29 Correct BOM: K40 laser module not yet in hand, only 3 items left to order
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2026-07-29 Adopt Ortur's own X/Y axis convention (0043)
    Supersedes 0014's project-invented reversed naming. Now matches the
    reused Ortur controller/firmware/wiring's own labeling: Y = long
    1200mm axis (dual-motor gantry travel), X = short 800mm axis (beam
    carriage). All 18 prior ADRs still use the old convention in their
    text - 0043 documents the swap explicitly since letters in those files
    are no longer authoritative, only the physical facts are.
2026-07-29 Fix 0043: gantry rides the 800mm axis, not 1200mm (per user correction)
    Got the topology backwards from web research on Ortur's stock kit
    numbers. Per the user directly: on this machine, Y (gantry/rail/
    dual-motor axis) is 800mm - the stock kit's max - and X (beam/carriage/
    single-motor axis) is 1200mm from a separate custom beam elongation
    beyond stock. This reverses 0014's original short-beam rationale, but
    matches the machine's actual already-proven geometry.
2026-07-29 Fix 0041/0043/BOM: Y is single motor + extended shaft, not dual motor
    Per user correction: the Ortur's gantry/rail (Y, 800mm) axis uses ONE
    NEMA17 with its shaft extended via coupler + standoff to drive both
    sides from a single continuous shaft - not two motors mechanically
    coupled. Squaring is inherent to the single-shaft mechanism, not a
    synced-pair concern. Only 2 motors total needed (1 Y + 1 X), corrected
    motor mount bracket quantity accordingly.
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2026-07-30 Revert to K40 - already ordered (0045)
    Supersedes 0044's K30 switch. Power headroom argument: can always dial
    a K40 down to K30-equivalent power for routine 3/6mm jobs, can't dial a
    K30 up past its own capacity for anything thicker/denser later. User has
    already placed the K40 order. BOM/weight-budget references reverted to
    K40 throughout.
2026-07-31 Revert to shaft-driven open belt loops, both sides (0046)
    Supersedes 0042's captured-under-wheel routing. Motor + extended shaft
    now drives a pulley at each end feeding a conventional open belt loop
    per side, clamped at the carriage - avoids needing to match the
    purchased aluminum plate's exact wheel geometry, and reinstates already-
    purchased hardware (Socobeta mounts, BEMONOC/DiGiYes pulleys, 3DMAN
    clamps) that 0042 had sidelined. New open task: motor-mount plate +
    shaft-support/standoff mount, both attaching to the aluminum plates.
2026-07-31 Revert to captured belt drive with custom laser-cut Y gantry plates (0047)
    Supersedes 0046's open-belt-loop reversion - with real reference
    geometry from Printables/yplateleft.stl and yplateright.stl now in hand,
    captured-belt is no longer a fitting problem. New design:
    hardware/laser-cut/y-gantry-plate.svg, two variants (motor/bearing),
    5mm black acrylic, reusing wheels/bolts from the purchased aluminum
    V-wheel plate kit. 2 top wheels + 3 bottom wheels (vs reference's 2+1),
    plus 4 M5 holes per plate for 20-series corner L-brackets seated in the
    2040's V-slot for rigidity. Superseded 3D-printed drafts
    (y-gantry-plate.scad, shaft-far-end-bearing-mount.scad) kept for
    reference/coordinate histo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
    [shaft-far-end-bearing-mount.scad, shaft-far-end-bearing-mount.stl, y-gantry-plate-bearing.stl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]
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2026-07-31 Replace Y gantry plate with user-authored final design (0047)
    Supersedes the programmatic draft entirely. Real attachment scheme:
    6 points per plate to the 2040 beam - 2 tapped directly into the
    extrusion end, 4 through slotted L-bracket holes (slotted deliberately,
    no reliable reference exists for that hardware's exact spacing).
    BOM/ADR updated to match.
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2026-07-31 Add xplatefront cross-hole symmetry comparison (original vs corrected)
    Cross-pattern holes on the K40 laser-slide mount were asymmetric in the
    source STL: 20mm vertical / 25mm horizontal arm spacing from center.
    Corrected version averages both to a symmetric 22.5mm. Corner holes
    (7.2mm bottom, 5.2mm top) and the 85x85mm outline unchanged - side by
    side comparison for review before cutting.
2026-07-31 Add direct 1:1 trace of V-slot corner connector (L_type.stl) for reference
    Source: user's downloaded model, "Corner connector for the V-slot -
    6103466". Genuinely flat 3mm plate (not a bent bracket) - triangular
    gusset, 60mm square with the far corner chamfered diagonally. 5x 5mm
    mounting holes: shared corner hole + 2 more per leg, 20mm apart.
    Candidate for cutting these in-house instead of buying, to help keep
    the frame square.
2026-08-02 Add direct 1:1 trace of GT2 belt end-clamp for reference
    Source: user's downloaded model, "Gt2 belt hoder - 6465304". Small
    vertical part, 10x20mm, 2.5mm thick. Belt slot (7x2.5mm) near the top
    where the belt passes through and gets pinched; mounting screw hole
    (~5.4mm) near the bottom for attaching to the carriage. For sizing a
    matching slot in the gantry plate that was missed in the original design.
2026-08-02 Captured belt on both axes, eliminate idler pulleys (0048)
    Extends 0047 from Y-only to both axes - captured belt doesn't need a
    separate idler pulley, the drive pulley mounts between the wheels
    directly. Cleaned out hardware/3d-printed/ entirely (all prior drafts
    superseded, git history preserves them) and added gt2-fixing-clamp.stl
    as the sole remaining 3D-printed part, qty 8, anchoring the captured
    belt's ends on both axes. BOM/ADRs updated throughout.
    [gt2-fixing-clamp.stl, limit-switch-mount.scad, limit-switch-mount.stl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]
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2026-08-03 Add 3D-printed OLMP-V1.2C board mount (interim, no laser running yet)
    L-bracket: wall carries the board's 2 M3 holes (15.5mm apart), base
    has a T-nut slide slot for position adjustment along the extrusion.
    Geometry taken from the user's FRONT/TOP/SIDE reference sketch.
    [olmp-board-mount.scad, olmp-board-mount.stl]
2026-08-03 Rebuild OLMP board mount as a literal translation of the reference sketch
    Removed the invented gusset/wall/base split - the part is now the
    FRONT profile's exact outline (curve tessellated from the SVG bezier
    path) extruded through the TOP-layer depth, one solid piece since it
    prints solid PLA-CF. M3 holes and M5 slide slot use the drawing's
    exact positions/sizes rather than rounded engineering values. Slot
    extended to a true through-cut so the bolt is reachable from the top.
    [olmp-board-mount.scad, olmp-board-mount.stl]
2026-08-03 Rebuild OLMP board mount as a genuine L-bracket, not a solid wedge
    The FRONT profile is the wall's own thin (2.5mm) silhouette, not a
    solid cross-section - matches the SIDE layer's two ~2.4mm rectangles,
    which is an actual L cross-section, not annotation. Foot is now a
    separate thin plate at the wall's base. M5 slot runs through the foot
    only, parallel to the front wall; M3 holes through the wall only.
    [olmp-board-mount.scad, olmp-board-mount.stl]
2026-08-03 Narrow OLMP mount wall to sit left-aligned within the wider foot
    Reflects the user's edit to the FRONT layer of the reference SVG: the
    wall is now 29.55mm wide (was 40.08mm, matching the foot), left edges
    aligned, wall narrower than the foot intentionally. Holes shifted left
    with the wall, same height/spacing as before.
    [olmp-board-mount.scad, olmp-board-mount.stl]
2026-08-03 Center the OLMP mount's slide slot depth-wise in the foot
    Was 10.86mm from the near edge (TOP layer's drawn position, off
    center); now centered at 14.19mm so there's equal clearance for the
    bolt head front and back.
    [olmp-board-mount.scad, olmp-board-mount.stl]
2026-08-06 Update BOM for the built/running machine, add control-system spares list
    Machine is built and operational (2026-08-06). Records the real final
    wiring: K40's bundled adapter board isn't used (never passed PWM), fixed
    by direct-wiring the Ortur mainboard's own LA_PWM/LA_PWR/GND pins to the
    K40's screw terminals via a spliced spare harness. Power now runs off
    the K40's bundled 24V/8A PSU, not the Mean Well (kept as a spare).
    Adds a standalone "control system quick-reference" section scoped to
    just the controller/power/laser-firing chain, for fast lookup if the
    controller ever needs replacing.
2026-08-06 Correct BOM: K40 harness is the LU2-10A's own cable, not a spare
    The direct-wire fix reused the LU2-10A's original power/GND/PWM cable,
    cut and re-terminated for the K40's screw terminals - it wasn't a
    second spare harness. The LU2-10A currently has nothing plugged into
    it as a result, so there's no swap-back fallback and no spare copy of
    this harness if it ever needs rebuilding.
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
